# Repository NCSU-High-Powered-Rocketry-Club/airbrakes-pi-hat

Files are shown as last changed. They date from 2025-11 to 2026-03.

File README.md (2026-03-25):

# airbrakes-pi-hat

Custom made Pi hat, named "Airbender", for use in Airbrakes

This repository contains the KiCad project files for a Raspberry Pi hat. This Pi hat is meant to control
airbrakes (see the [airbrakes repository](https://github.com/NCSU-High-Powered-Rocketry-Club/AirbrakesV2) for more details on the airbrakes system).

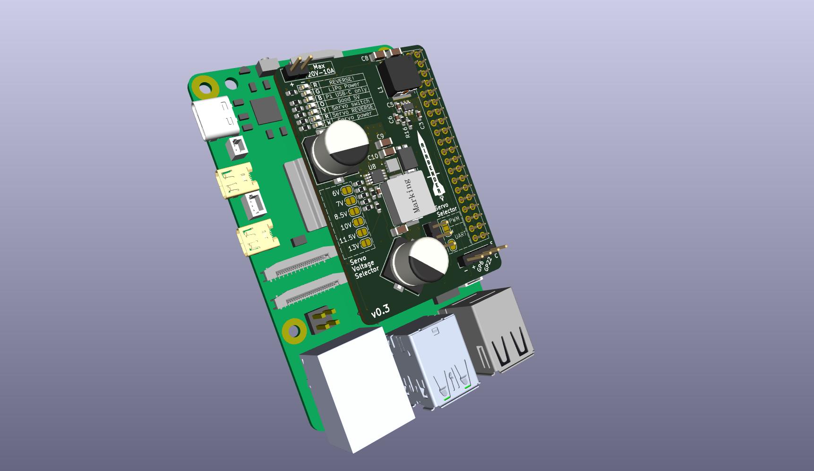
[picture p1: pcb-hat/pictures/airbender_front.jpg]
Airbender Front

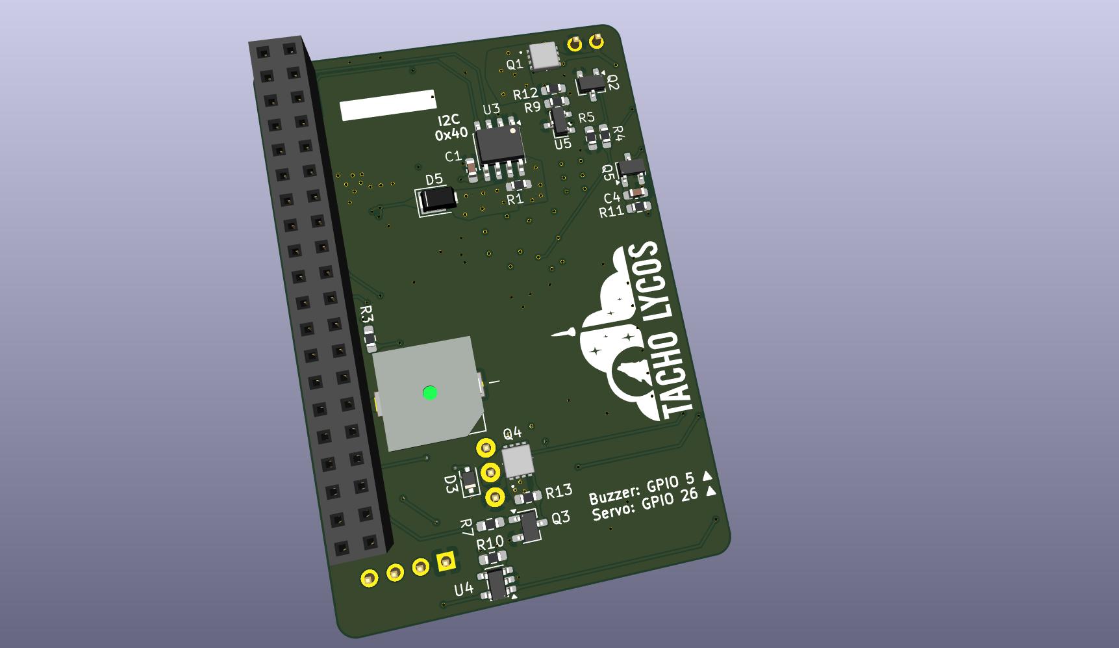
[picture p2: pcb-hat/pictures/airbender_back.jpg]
Airbender Back


## Features

- Supports from 7V to 20V input voltage, with a maximum amperage of 10A.
- Variable output voltage for the servo power rail (6V to 13V), while simultaneously powering the Pi at 5V.
- Current and voltage sensing for the entire board, which allows measurement of servo load transients.
- Reverse polarity detection and protection on the input power rail
- Reverse polarity detection and protection for the servo cable. Plugging in the cable backwards now will not fry the Raspberry Pi.
- 7 LEDs for monitoring and detecting the health of the board and its interface with the Raspberry Pi.
- Solder jumper pad to select using a servo via PWM or communicate with the servo via UART
- P-MOSFET to disable power to the servo rail when not in use
- Software controlled buzzer for audible alerts

The repository includes schematic symbols, PCB footprints, 3D models, and all board files necessary to review, edit and manufacture the module.

---

## Quick Start — open the project

1. Install KiCad (see [Install and Setup](#install-and-setup) below).
2. Clone the repository:
```bash
git clone https://github.com/NCSU-High-Powered-Rocketry-Club/airbrakes-pi-hat.git && cd airbrakes-pi-hat
```

---

## Install and Setup

First, install KiCad from [kicad.org](https://kicad.org/download/). We recommend using the latest stable release of KiCad for new designs.

### After installation
- Open the `pcb-hat.kicad_pro` project. KiCad will use the `sym-lib-table` and `fp-lib-table` files included here if you open the board/schematic from this checkout.
- If KiCad shows missing library warnings, update the Project Library Tables or use the library manager to add the project's `sym-lib-table` and `fp-lib-table`.

---

## Repository structure

Root-level description (key files/folders):

- `milled_ab_pi_hat/` — folder containing CNC milling files for in-house fabrication at the ECE Makerspace
- `pcb-hat/` — folder which contains the project files for the SMD version of the Pi hat (This is what we order from JLCPCB!)
- `pcb-hat.kicad_sch` — schematic
- `pcb-hat.kicad_pcb` — PCB layout
- `pcb-hat.kicad_pro` — KiCad project file that links schematics, board and library tables
- `sym-lib-table` — project symbol library table that makes project-local symbols available to Eeschema
- `fp-lib-table` — project footprint library table that makes project-local footprints available
- `3dmodels/` — 3D STEP/WRL models used with footprints
- `symbols/` — human-editable symbol libraries (e.g., `connectors.kicad_sym`, `sensors.kicad_sym`)
- `footprints/` — footprint libraries as `.pretty` directories

---

## Library handling

We keep the project-specific libraries inside the repository so that board designs are reproducible and self-contained.

### Symbols
- New symbols are added to the project's `symbols` directory and are registered in the project's `sym-lib-table`.

### Footprints
- Footprints live inside `.pretty` folders in `footprints/`. Add footprints via the footprint editor and store them in an appropriate `footprints/<libname>.pretty` folder.

### 3D models
- 3D models are stored in `3dmodels/` and referenced by footprint model paths. Keep STEP files with good orientation and scale (KiCad's default is mm). We typically download the .step file from the manufacturer's website.
- If you add a footprint that references a 3D model, commit both the footprint in `footprints/` and the 3D model to `3dmodels/`.

---

## Good Practices & Design Rules

- Keep schematic symbols generic and footprints specific: do not hardcode assembly-side changes into symbols.
- Look at the existing schematic to see how we do things and try to be consistent.
- Save new libraries to the project-local tables (not global) to keep designs reproducible.
- Keep PCB footprints accurate — use accurate courtyard, 3D models, and update packaging information.
- Validate with DRC (PCB Editor > Inspect > Design Rules Checker) and ERC (Eeschema > Tools > ERC) before committing changes.
- When collaborating, include notes about part sources (Mouser/Digikey vendor links), footprints used, and any custom pad or thickness changes.

---

## Release & Manufacturing Checklist

Before requesting fab or assembling a board, run this checklist:
1. Run ERC (Eeschema > Tools > ERC) and fix all warnings.
2. Run DRC in PCB Editor and resolve all errors.
3. Create a BOM and confirm manufacturer part numbers and footprints match.
4. Get the [Fabrication Toolkit](https://github.com/bennymeg/Fabrication-Toolkit) plugin from the KiCad plugin repo
5. Click the generate gerber files button in the PCB editor (via the plugin). Keep all default options. Then export it. 
6. Check 3D model alignment in PCB Editor (View > 3D Viewer) to ensure components fit.
7. Tag or branch the repo in Git to preserve the release snapshot.

---

## License

See `LICENSE` at the repo root for licensing details.

---

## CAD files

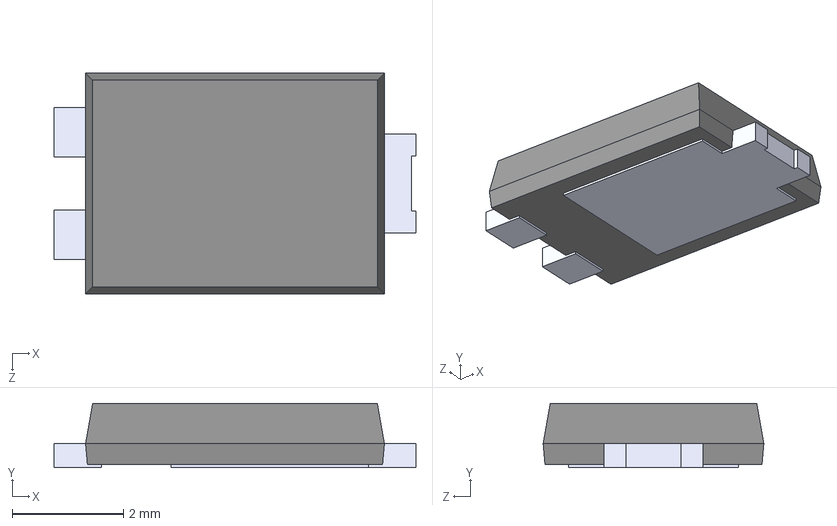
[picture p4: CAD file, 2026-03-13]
pcb-hat/3dmodels/SBR10E45P5-13D.STEP
6.50 x 1.15 x 3.97 mm

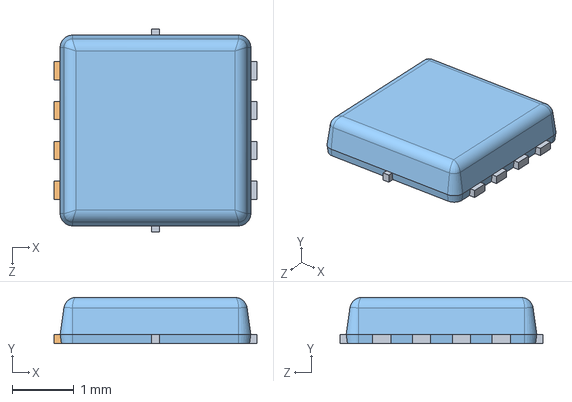
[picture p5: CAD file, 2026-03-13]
pcb-hat/3dmodels/PJQ4437EP-AU.stp
3.30 x 0.75 x 3.30 mm
LeadFrame
EMC

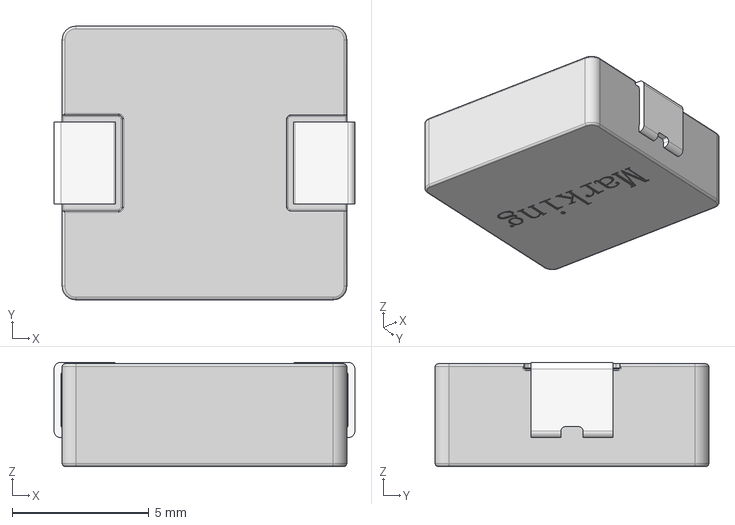
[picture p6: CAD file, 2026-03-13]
pcb-hat/3dmodels/3D_SRP1038CC SERIES(leadframe type).stp
11.0 x 10.0 x 3.81 mm

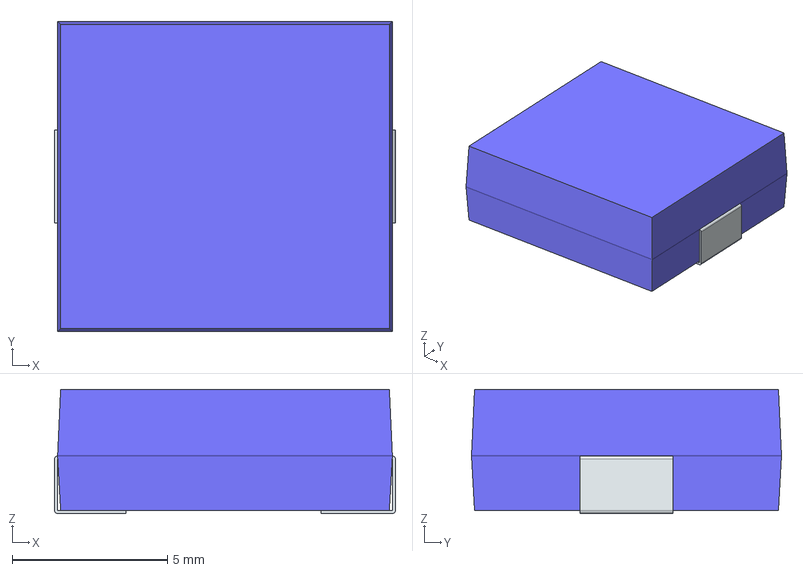
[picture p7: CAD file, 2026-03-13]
pcb-hat/3dmodels/SRP1038CC-4R7M.stp
11.0 x 10.0 x 4.00 mm
FilletPin1
FilletPin2

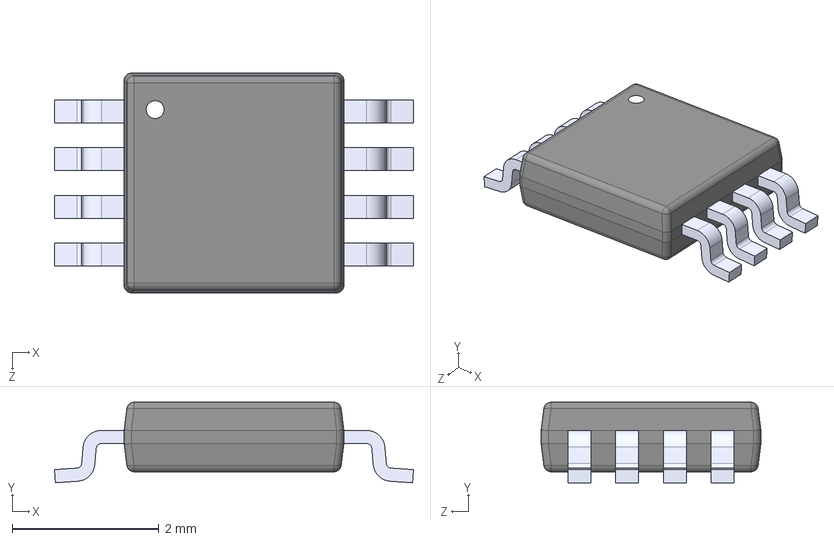
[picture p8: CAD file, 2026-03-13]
pcb-hat/3dmodels/LM3489MMX_NOPB.step
4.90 x 1.10 x 3.00 mm

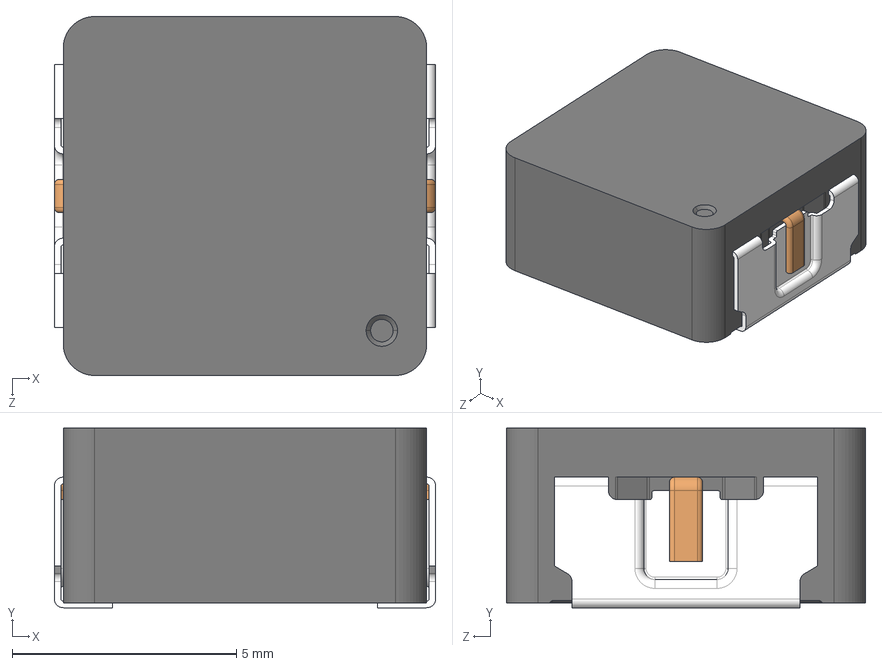
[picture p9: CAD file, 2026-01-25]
pcb-hat/3dmodels/ETQP4M6R8KVK.step
8.50 x 4.00 x 8.00 mm

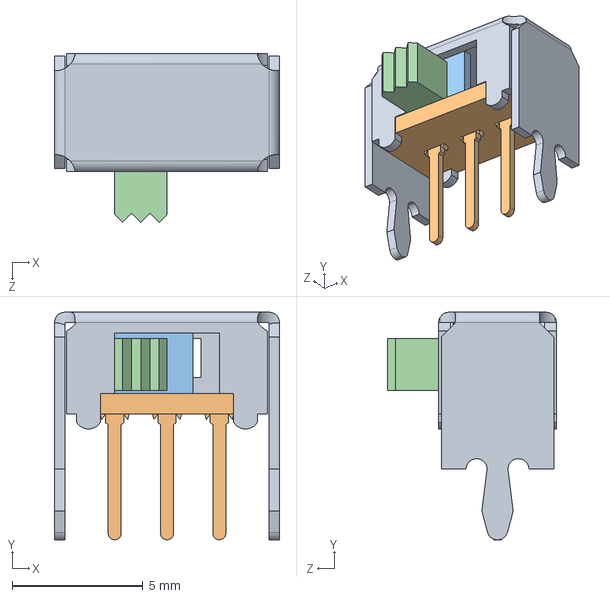
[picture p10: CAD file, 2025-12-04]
pcb-hat/3dmodels/SLW-864587-2A-RA-N-D.step
8.60 x 8.70 x 6.45 mm

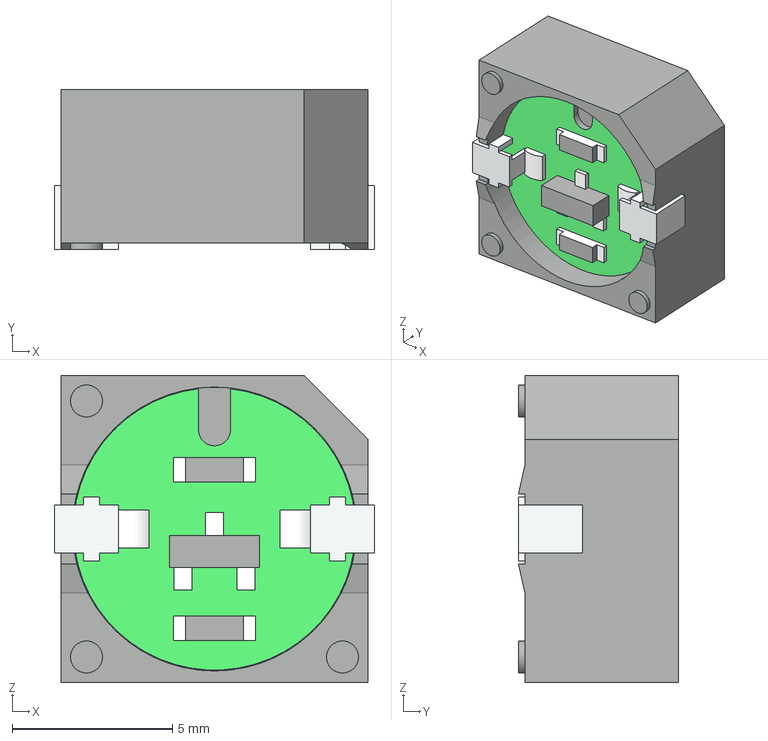
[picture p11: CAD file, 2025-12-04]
pcb-hat/3dmodels/SMI-1027-T-5V-R.step
10.0 x 5.00 x 9.60 mm

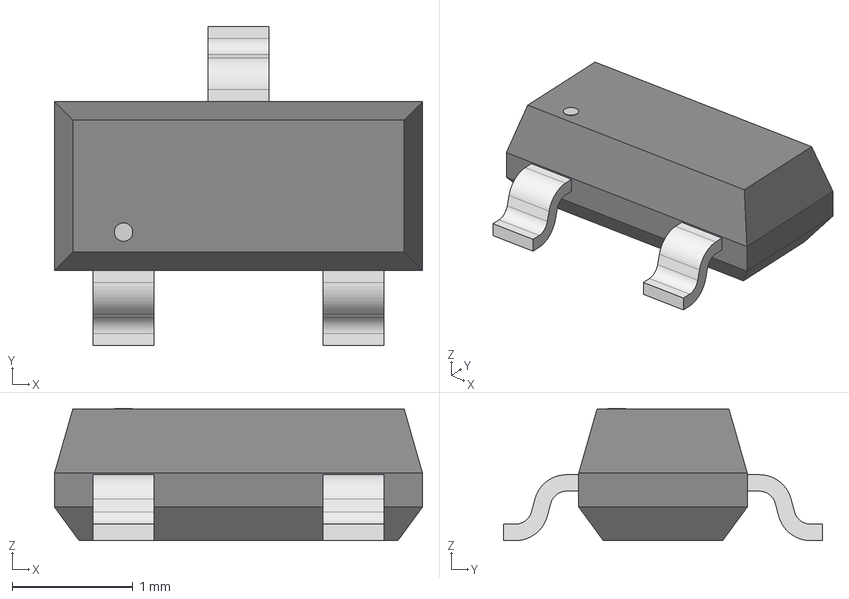
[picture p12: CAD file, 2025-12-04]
pcb-hat/3dmodels/MTR_MMBT2222A-TP_MCE.step
3.05 x 2.64 x 1.09 mm

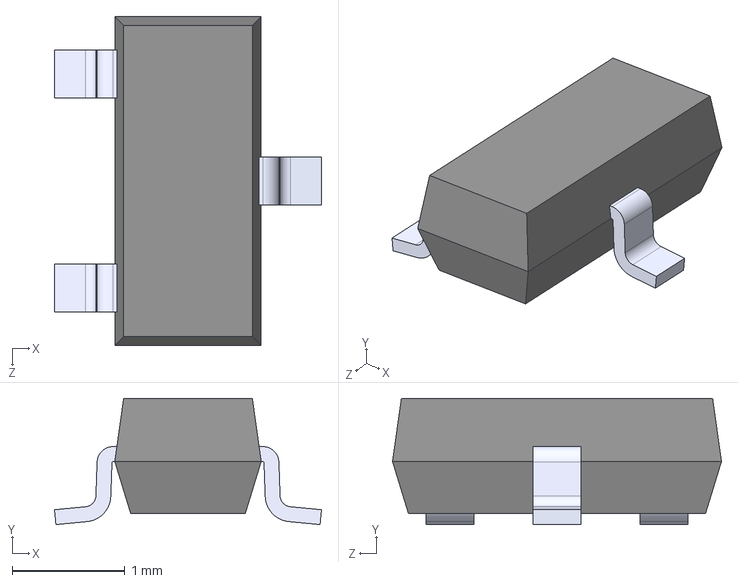
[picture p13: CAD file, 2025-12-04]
pcb-hat/3dmodels/SI2347DS-T1-GE3.STEP
2.37 x 1.12 x 2.92 mm

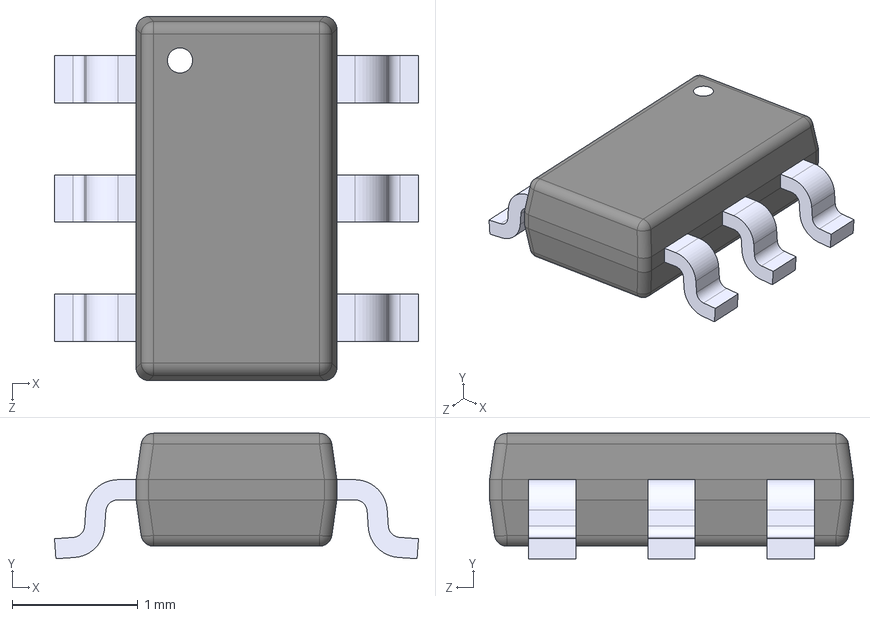
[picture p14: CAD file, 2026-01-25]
pcb-hat/3dmodels/AP63300WU-7.step
2.90 x 1.00 x 2.90 mm

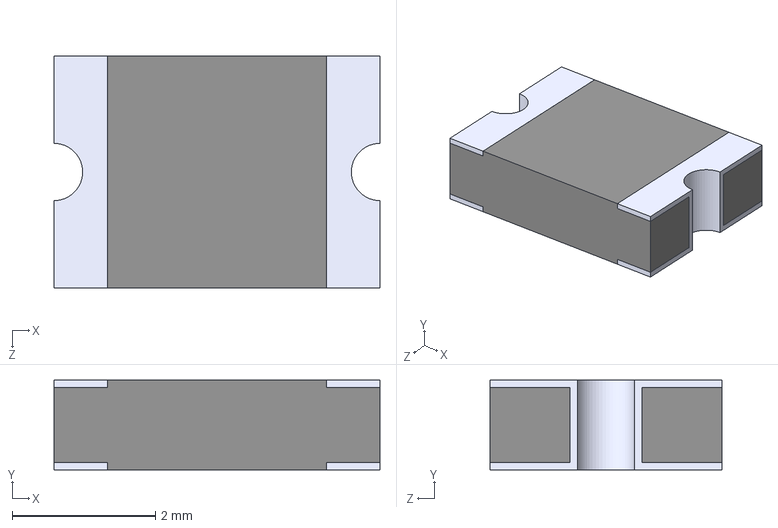
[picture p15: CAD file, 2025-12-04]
pcb-hat/3dmodels/1812L110_24DR.step
4.55 x 1.25 x 3.24 mm

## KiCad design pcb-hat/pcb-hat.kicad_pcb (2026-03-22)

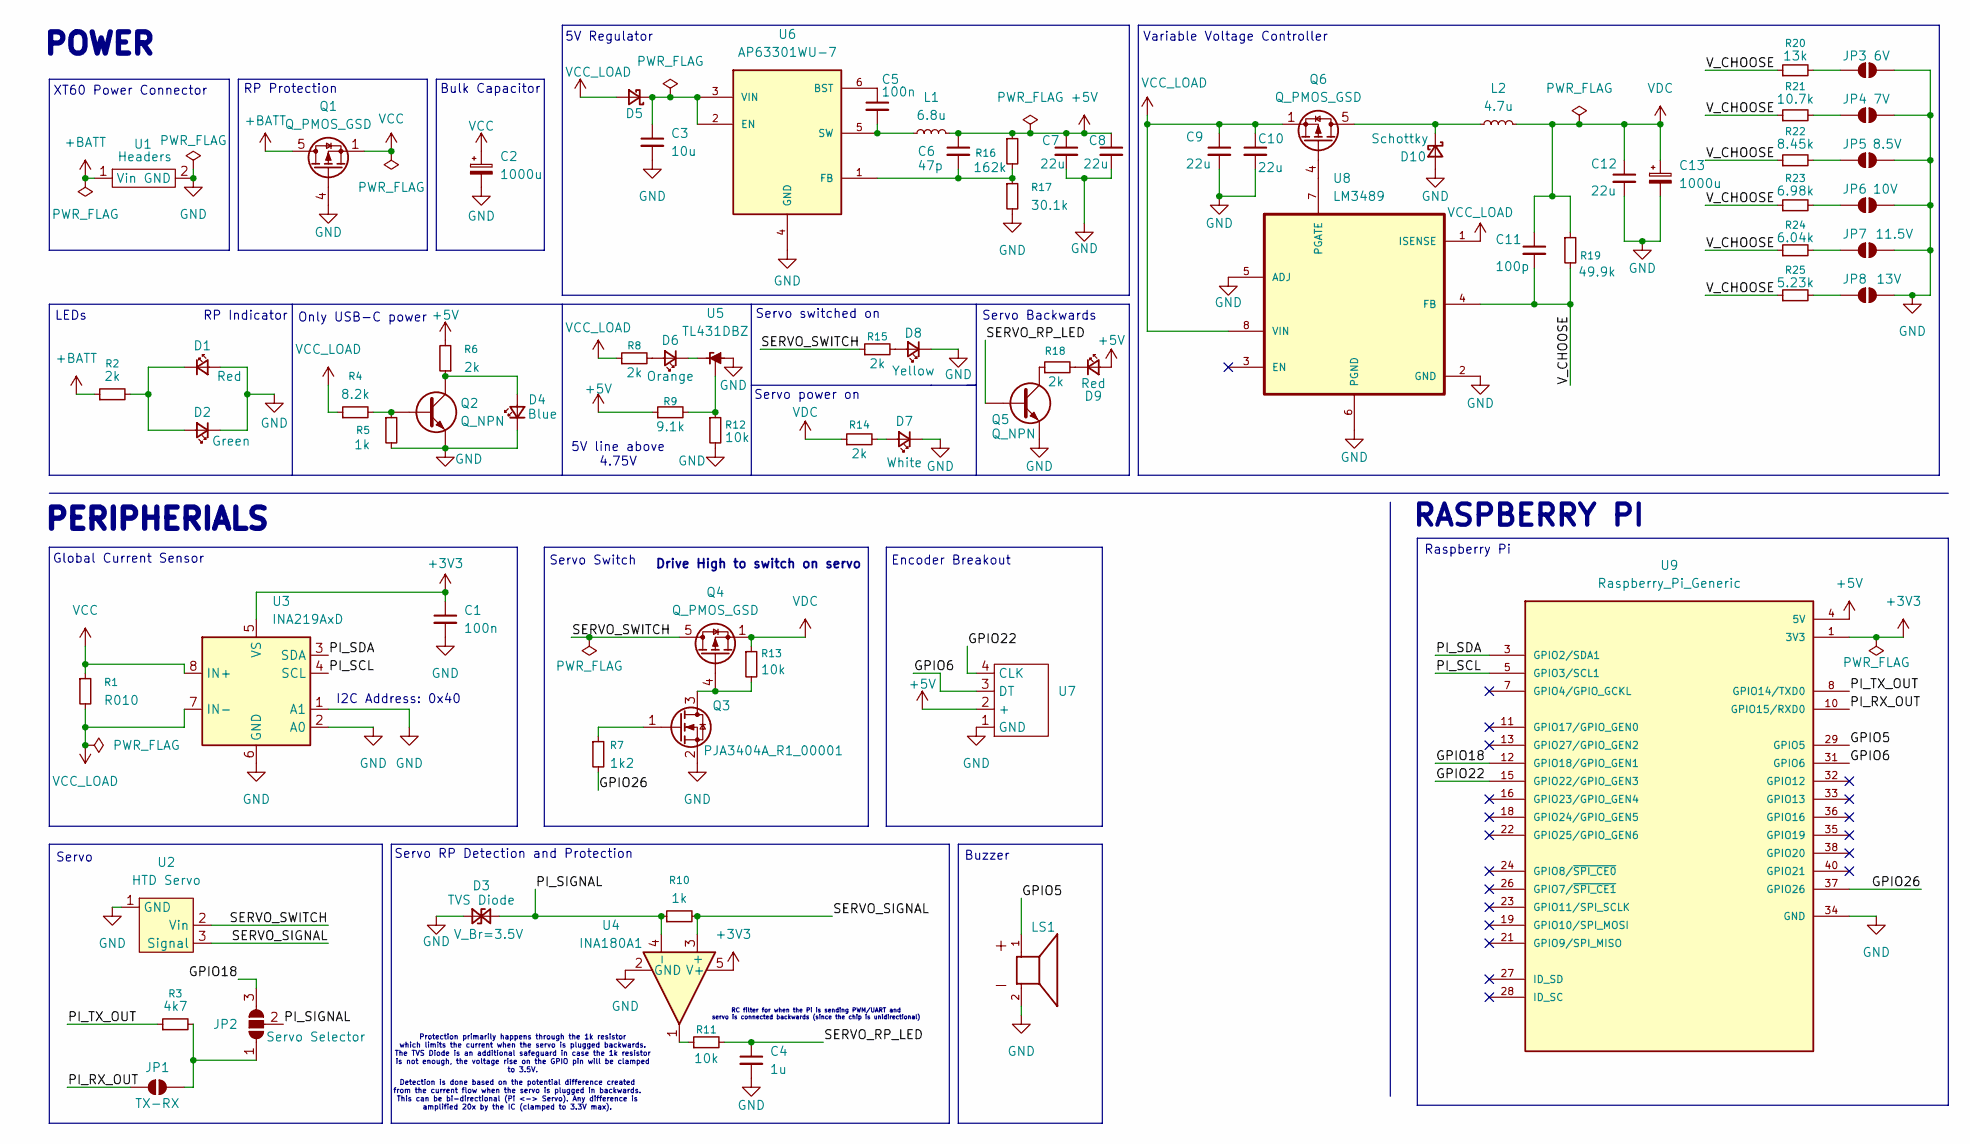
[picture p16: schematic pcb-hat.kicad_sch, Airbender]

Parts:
C1, C5: 100n; C_0603_1608Metric_Pad1.08x0.95mm_HandSolder; Digikey PN C0603C104K3RACTU
C2, C13: 1000u; CP_Elec_10x10.5; Digikey PN 399-A783MW108M1ELAS011CT-ND
C3: 10u; C_0603_1608Metric_Pad1.08x0.95mm_HandSolder; Digikey PN 1276-1869-1-ND
C4: 1u; C_0603_1608Metric_Pad1.08x0.95mm_HandSolder; Digikey PN 587-3247-1-ND
C6: 47p; C_0603_1608Metric_Pad1.08x0.95mm_HandSolder; Digikey PN 720-VJ0603A470JXXPW1BCCT-ND
C7, C8, C9, C10, C12: 22u; C_1206_3216Metric; Digikey PN 587-3246-1-ND
C11: 100p; C_0603_1608Metric_Pad1.08x0.95mm_HandSolder; Digikey PN 399-C0603C101J5GACTUCT-ND
D1, D9: LED_Small; LED_0603_1608Metric_Pad1.05x0.95mm_HandSolder; Digikey PN 475-LSQ976.01-N1Q2-1-20-R18CT-ND
D2: LED_Small; LED_0603_1608Metric_Pad1.05x0.95mm_HandSolder; Digikey PN 160-LTST-C190GKTCT-ND
D3: TVS Diode; D_SOD-323F; Digikey PN F6271CT-ND
D4: LED_Small; LED_0603_1608Metric_Pad1.05x0.95mm_HandSolder; Digikey PN 160-1837-1-ND
D5: SS3P4-M3/84A; D_SMP_DO-220AA; Digikey PN SS3P4-M3/84AGICT-ND
D6: LED_Small; LED_0603_1608Metric_Pad1.05x0.95mm_HandSolder; Digikey PN 475-LOQ976.01-P2R2-25-1-20-R18CT-ND
D7: LED_Small; LED_0603_1608Metric_Pad1.05x0.95mm_HandSolder; Digikey PN 350-5992000147FCT-ND
D8: LED_Small; LED_0603_1608Metric_Pad1.05x0.95mm_HandSolder; Digikey PN 160-1437-1-ND
D10: Schottky; D_PowerDI-5; Digikey PN SBR10E45P5-7DICT-ND
JP1: TX to RX?; SolderJumper-2_P1.3mm_Open_RoundedPad1.0x1.5mm
JP2: Servo Selector; SolderJumper-3_P1.3mm_Open_RoundedPad1.0x1.5mm
JP3, JP4, JP5, JP6, JP7, JP8: SolderJumper_2_Open; SolderJumper-2_P1.3mm_Open_RoundedPad1.0x1.5mm
L1: 6.8u; IND_ETQP4M6R8KVK; Digikey PN P19775CT-ND
L2: 4.7u; L_Bourns_SRP1038C_10.0x10.0mm; Digikey PN SRP1038CC-4R7M
LS1: XDCR_SMI-1027-T-5V-R; PARTREV 03/26/2020; Digikey PN smi-1027-t-5v-r
Q1, Q4, Q6: Q_PMOS_GSD; PJQ4465APAU_R2_000A1; Digikey PN 3757-PJQ4437EP-AU_R2_002A1CT-ND
Q2, Q5: Q_NPN; TSOT-23; Digikey PN MMBT2222A-TP
Q3: PJA3404A_R1_00001; TSOT-23; Digikey PN 3757-PJA3404A_R1_00001CT-ND
R1: R010; R_0603_1608Metric_Pad0.98x0.95mm_HandSolder; Digikey PN PE0603FRE570R01Z
R2, R6, R8, R14, R15: 2k; R_0603_1608Metric_Pad0.98x0.95mm_HandSolder; Digikey PN ERJ-PA3J202V
R3: 4k7; R_0603_1608Metric_Pad0.98x0.95mm_HandSolder; Digikey PN RC0603FR-074K7L
R4: 8.2k; R_0603_1608Metric_Pad0.98x0.95mm_HandSolder; Digikey PN 311-8.2KGRCT-ND
R5, R10: 1k; R_0603_1608Metric_Pad0.98x0.95mm_HandSolder; Digikey PN RMCF0603FT1K00CT-ND
R7: 1k2; R_0603_1608Metric_Pad0.98x0.95mm_HandSolder; Digikey PN ERA-3AEB122V
R9: 9.1k; R_0603_1608Metric_Pad0.98x0.95mm_HandSolder; Digikey PN RMCF0603FT9K10CT-ND
R11, R12, R13: 10k; R_0603_1608Metric_Pad0.98x0.95mm_HandSolder; Digikey PN 311-10.0KHRCT-ND
R16: 162k; R_0603_1608Metric_Pad0.98x0.95mm_HandSolder; Digikey PN 541-162KHCT-ND
R17: 30.1k; R_0603_1608Metric_Pad0.98x0.95mm_HandSolder; Digikey PN RMCF0603FT30K1CT-ND
R18: 2k; R_0603_1608Metric_Pad0.98x0.95mm_HandSolder; Digikey PN RMCF0603FT1K00CT-ND
R19: 49.9k; R_0603_1608Metric_Pad0.98x0.95mm_HandSolder; Digikey PN P49.9KDBCT-ND
R20: 13k; R_0603_1608Metric_Pad0.98x0.95mm_HandSolder; Digikey PN 2019-RK73H1JTTD1302FCT-ND
R21: 10.7k; R_0603_1608Metric_Pad0.98x0.95mm_HandSolder; Digikey PN 311-10.7KHRCT-ND
R22: 8.45k; R_0603_1608Metric_Pad0.98x0.95mm_HandSolder; Digikey PN 311-8.45KHRCT-ND
R23: 6.98k; R_0603_1608Metric_Pad0.98x0.95mm_HandSolder; Digikey PN 10-ERA-3AEB6981VCT-ND
R24: 6.04k; R_0603_1608Metric_Pad0.98x0.95mm_HandSolder; Digikey PN 311-6.04KHRCT-ND
R25: 5.23k; R_0603_1608Metric_Pad0.98x0.95mm_HandSolder; Digikey PN 311-5.23KHRCT-ND
U1: Headers; XT60
U2: HTD Servo; Servo
U3: INA219AxD; SOIC-8_3.9x4.9mm_P1.27mm; Digikey PN INA219AIDR
U4: INA180A1; SOT-23-5; Digikey PN 296-47652-1-ND
U5: TL431DBZ; SOT-23; Digikey PN 5399-TL431CT-ND
U6: AP63301WU-7; SOT95P280X100-6N; Digikey PN 31-AP63301WU-7CT-ND
U7: PinHeader_1x04_P2.54mm_Vertical
U8: LM3489; SOP65P490X110-8N; Digikey PN 296-35277-1-ND
U9: Raspberry_Pi_Generic; Pi5Hat

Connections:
+3V3: C1.1, U3.5 (VS), U4.5 (V+), U9.1 (3V3), U9.17 (3V3)
+5V: C6.1, C7.1, C8.1, D9.2 (A), L1.2, R6.2, R9.1, R16.1, U7.2 (+), U9.2 (5V), U9.4 (5V)
+BATT: Q1.5 (D), Q1.6 (D), Q1.7 (D), Q1.8 (D), Q1.9 (D), R2.1, U1.1 (Vin)
/GPIO5: LS1.1, U9.29 (GPIO5)
/GPIO6: U7.3 (DT), U9.31 (GPIO6)
/GPIO18: JP2.3 (B), U9.12 (GPIO18/GPIO_GEN1)
/GPIO22: U7.4 (CLK), U9.15 (GPIO22/GPIO_GEN3)
/GPIO26: R7.2, U9.37 (GPIO26)
/PI_RX_OUT: JP1.1 (A), U9.10 (GPIO15/RXD0)
/PI_SCL: U3.4 (SCL), U9.5 (GPIO3/SCL1)
/PI_SDA: U3.3 (SDA), U9.3 (GPIO2/SDA1)
/PI_SIGNAL: D3.2 (A2), JP2.2 (C), R10.1, U4.4 (-)
/PI_TX_OUT: R3.1, U9.8 (GPIO14/TXD0)
/SERVO_RP_LED: C4.1, Q5.1 (B), R11.2
/SERVO_SIGNAL: R10.2, U2.3 (Signal), U4.3 (+)
/SERVO_SWITCH: Q4.5 (D), Q4.6 (D), Q4.7 (D), Q4.8 (D), Q4.9 (D), R15.1, U2.2 (Vin)
/V_CHOOSE: C11.2, R19.2, R20.1, R21.1, R22.1, R23.1, R24.1, R25.1, U8.4 (FB)
GND: C1.2, C2.2, C3.2, C4.2, C7.2, C8.2, C9.2, C10.2, C12.2, C13.2, D1.2 (A), D2.1 (K), D3.1 (A1), D4.1 (K), D7.1 (K), D8.1 (K), D10.2 (A), JP3.2 (B), JP4.2 (B), JP5.2 (B), JP6.2 (B), JP7.2 (B), JP8.2 (B), LS1.2, Q1.4 (G), Q2.2 (E), Q3.2 (S), Q5.2 (E), R5.2, R12.2, R17.2, U1.2 (GND), U2.1 (GND), U3.1 (A1), U3.2 (A0), U3.6 (GND), U4.2 (GND), U5.3 (A), U6.4 (GND), U7.1 (GND), U8.2 (GND), U8.5 (ADJ), U8.6 (PGND), U9.6 (GND), U9.9 (GND), U9.14 (GND), U9.20 (GND), U9.25 (GND), U9.30 (GND), U9.34 (GND), U9.39 (GND)
unnamed: D1.1 (K), D2.2 (A), R2.2
unnamed: D4.2 (A), Q2.3 (C), R6.1
unnamed: C3.1, D5.1 (K), U6.2 (EN), U6.3 (VIN)
unnamed: D6.2 (A), R8.2
unnamed: D6.1 (K), U5.1 (K)
unnamed: D7.2 (A), R14.2
unnamed: D8.2 (A), R15.2
unnamed: D9.1 (K), R18.2
unnamed: D10.1 (K), L2.1, Q6.5 (D), Q6.6 (D), Q6.7 (D), Q6.8 (D), Q6.9 (D)
unnamed: JP1.2 (B), JP2.1 (A), R3.2
unnamed: JP3.1 (A), R20.2
unnamed: JP4.1 (A), R21.2
unnamed: JP5.1 (A), R22.2
unnamed: JP6.1 (A), R23.2
unnamed: JP7.1 (A), R24.2
unnamed: JP8.1 (A), R25.2
unnamed: Q2.1 (B), R4.2, R5.1
unnamed: Q3.3 (D), Q4.4 (G), R13.2
unnamed: Q3.1 (G), R7.1
unnamed: Q5.3 (C), R18.1
unnamed: Q6.4 (G), U8.7 (PGATE)
unnamed: R11.1, U4.1
unnamed: R9.2, R12.1, U5.2 (REF)
unnamed: C5.1, U6.6 (BST)
unnamed: C6.2, R16.2, R17.1, U6.1 (FB)
unnamed: C5.2, L1.1, U6.5 (SW)
VCC: C2.1, Q1.1 (S), Q1.2 (S), Q1.3 (S), R1.1, U3.8 (IN+)
VCC_LOAD: C9.1, C10.1, D5.2 (A), Q6.1 (S), Q6.2 (S), Q6.3 (S), R1.2, R4.1, R8.1, U3.7 (IN-), U8.1 (ISENSE), U8.8 (VIN)
VDC: C11.1, C12.1, C13.1, L2.2, Q4.1 (S), Q4.2 (S), Q4.3 (S), R13.1, R14.1, R19.1

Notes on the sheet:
Global Current Sensor
Buzzer
PERIPHERIALS
Servo RP Detection and Protection
Servo
Encoder Breakout
LEDs
XT60 Power Connector
POWER
I2C Address: 0x40
Drive High to switch on servo
Servo Switch
Protection primarily happens through the 1k resistor which limits the current when the servo is plugged backwards. The TVS Diode is an additional safeguard in case the 1k resistor is not enough, the voltage rise on the GPIO pin will be clamped to 3.5V.
Servo power on
Servo switched on
Detection is done based on the potential difference created from the current flow when the servo is plugged in backwards. This can be bi-directional (Pi <-> Servo). Any difference is amplified 20x by the IC (clamped to 3.3V max).
Only USB-C power
RC filter for when the Pi is sending PWM/UART and servo is connected backwards (since the chip is unidirectional)
Bulk Capacitor
Variable Voltage Controller
RASPBERRY PI
5V line above 4.75V
RP Protection
5V Regulator
Raspberry Pi
Servo Backwards
RP Indicator

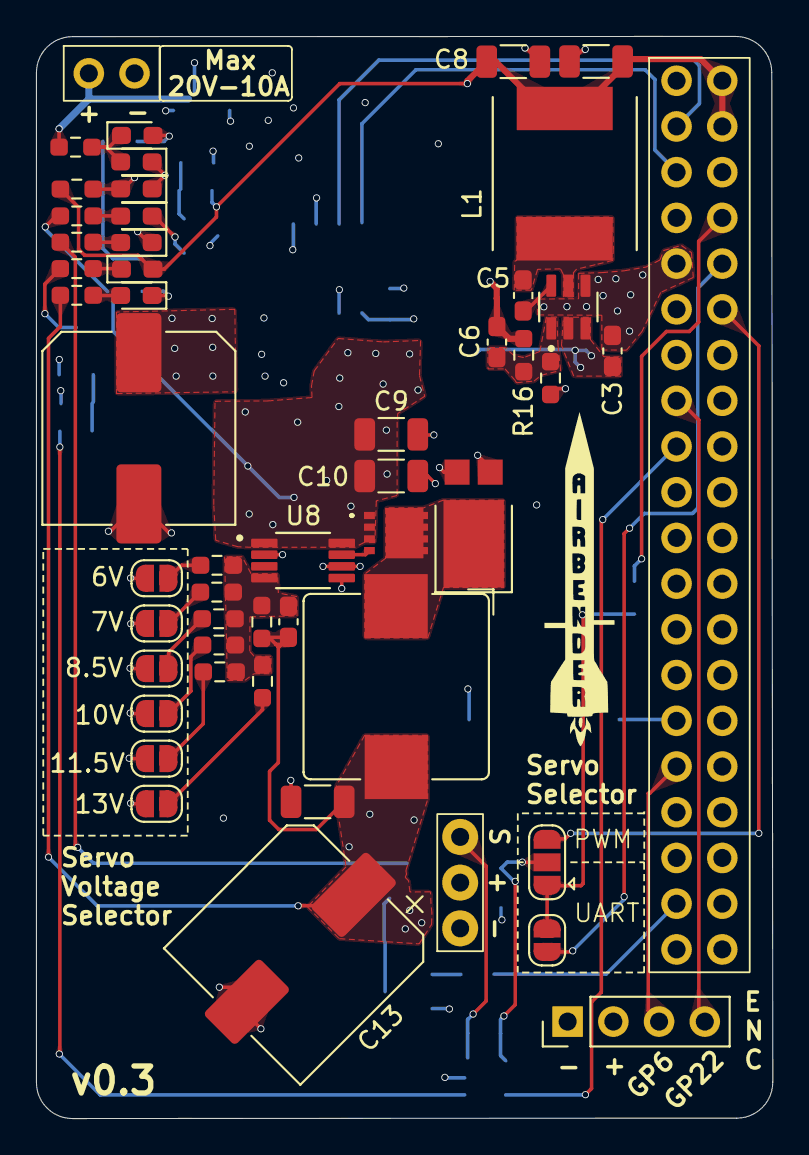
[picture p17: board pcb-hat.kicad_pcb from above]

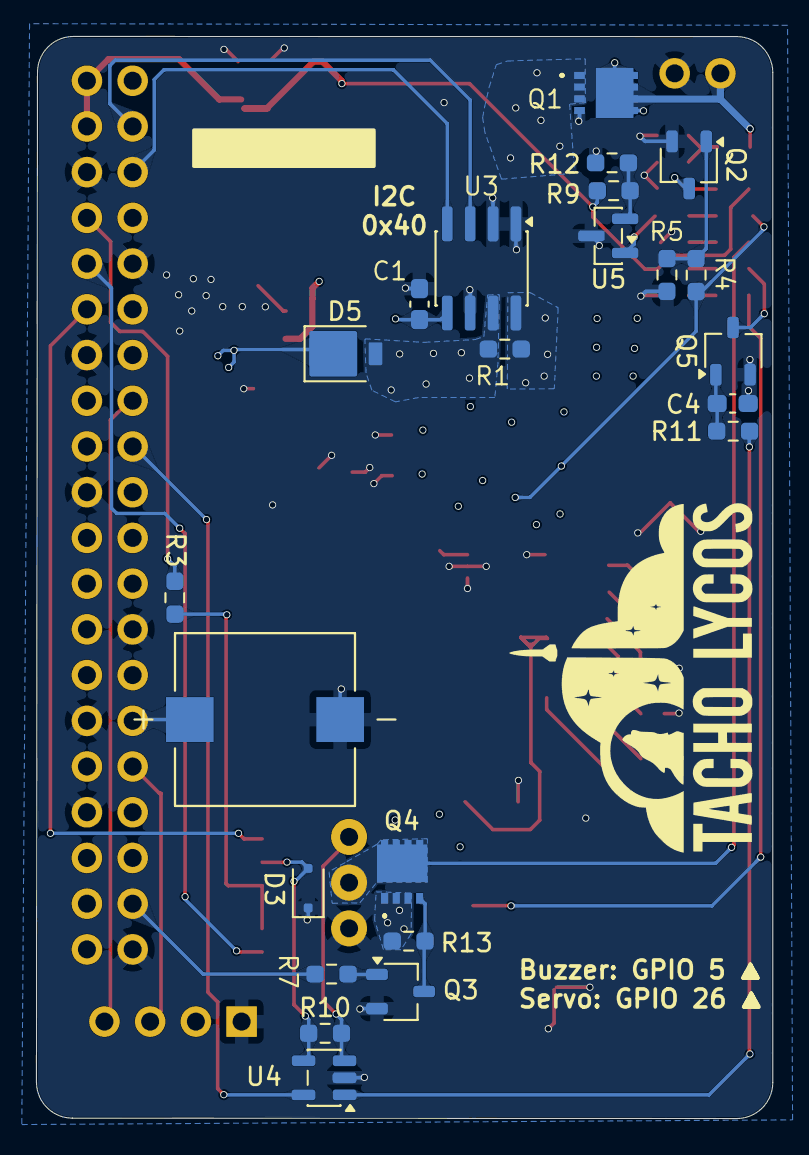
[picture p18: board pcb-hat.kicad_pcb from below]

Board: 4 copper layers, 40.9 x 60.1 mm, 75 parts (23 on the bottom side), 47 nets.

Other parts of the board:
RPi5: RPi5; Raspberry Pi 5

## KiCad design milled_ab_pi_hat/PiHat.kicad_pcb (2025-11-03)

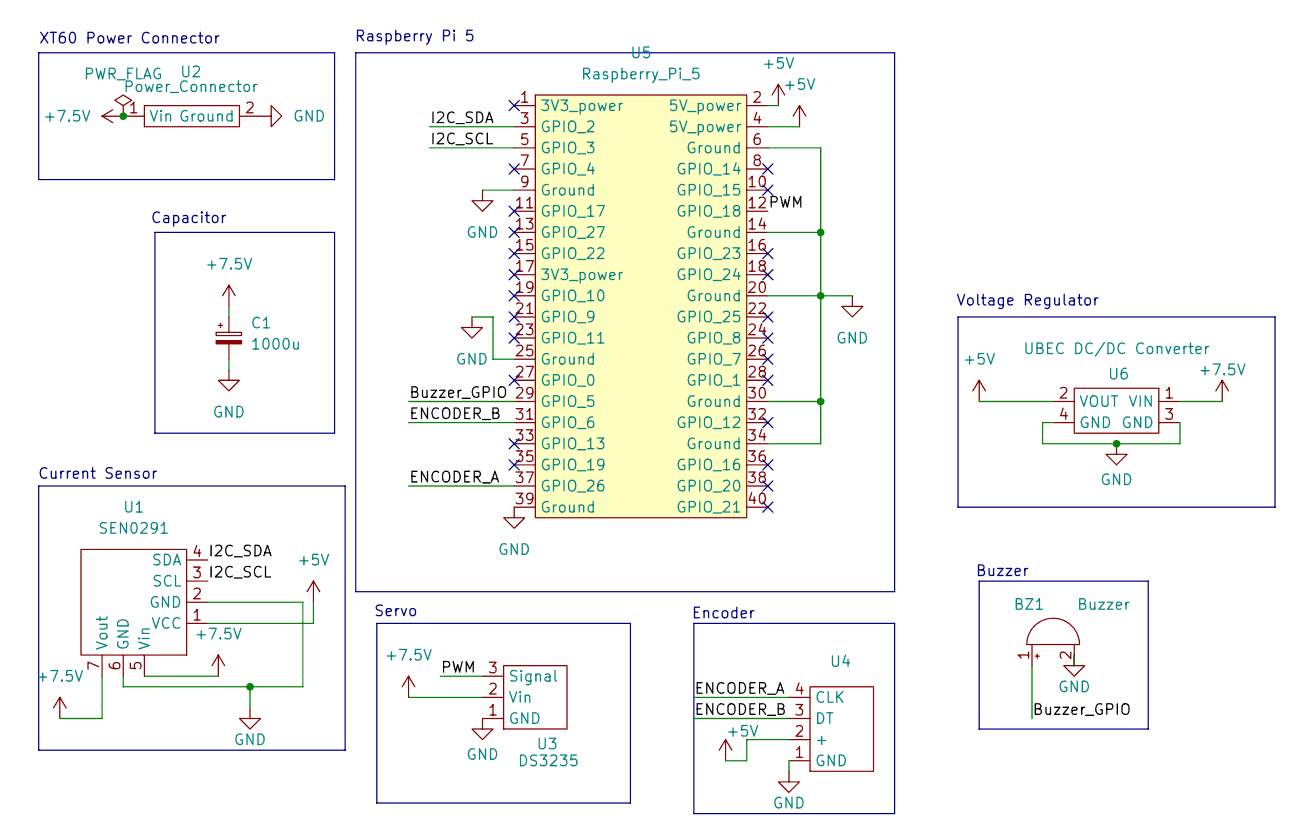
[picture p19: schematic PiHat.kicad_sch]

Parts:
BZ1: Buzzer; Buzzer_12x9.5RM7.6
C1: 1000u; BigCapacitor
U1: SEN0291; CurrentSensor
U2: Power_Connector; XT60
U3: DS3235; Servo
U4: Encoder
U5: Raspberry_Pi_5; Pi5Hat
U6: UBEC DC/DC Converter; UBEC 5V Step Down

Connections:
+5V: U1.1 (VCC), U4.2 (+), U5.2 (5V_power), U5.4 (5V_power), U6.2 (VOUT)
+7.5V: C1.1, U1.5 (Vin), U1.7 (Vout), U2.1 (Vin), U3.2 (Vin), U6.1 (VIN)
/Buzzer_GPIO: BZ1.1 (+), U5.29 (GPIO_5)
/ENCODER_A: U4.4 (CLK), U5.37 (GPIO_26)
/ENCODER_B: U4.3 (DT), U5.31 (GPIO_6)
/I2C_SCL: U1.3 (SCL), U5.5 (GPIO_3)
/I2C_SDA: U1.4 (SDA), U5.3 (GPIO_2)
/PWM: U3.3 (Signal), U5.12 (GPIO_18)
GND: BZ1.2 (-), C1.2, U1.2 (GND), U1.6 (GND), U2.2 (Ground), U3.1 (GND), U4.1 (GND), U5.6 (Ground), U5.9 (Ground), U5.14 (Ground), U5.20 (Ground), U5.25 (Ground), U5.30 (Ground), U5.34 (Ground), U5.39 (Ground), U6.3 (GND), U6.4 (GND)

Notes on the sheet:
Capacitor
Current Sensor
Encoder
XT60 Power Connector
Buzzer
Raspberry Pi 5
Servo
Voltage Regulator

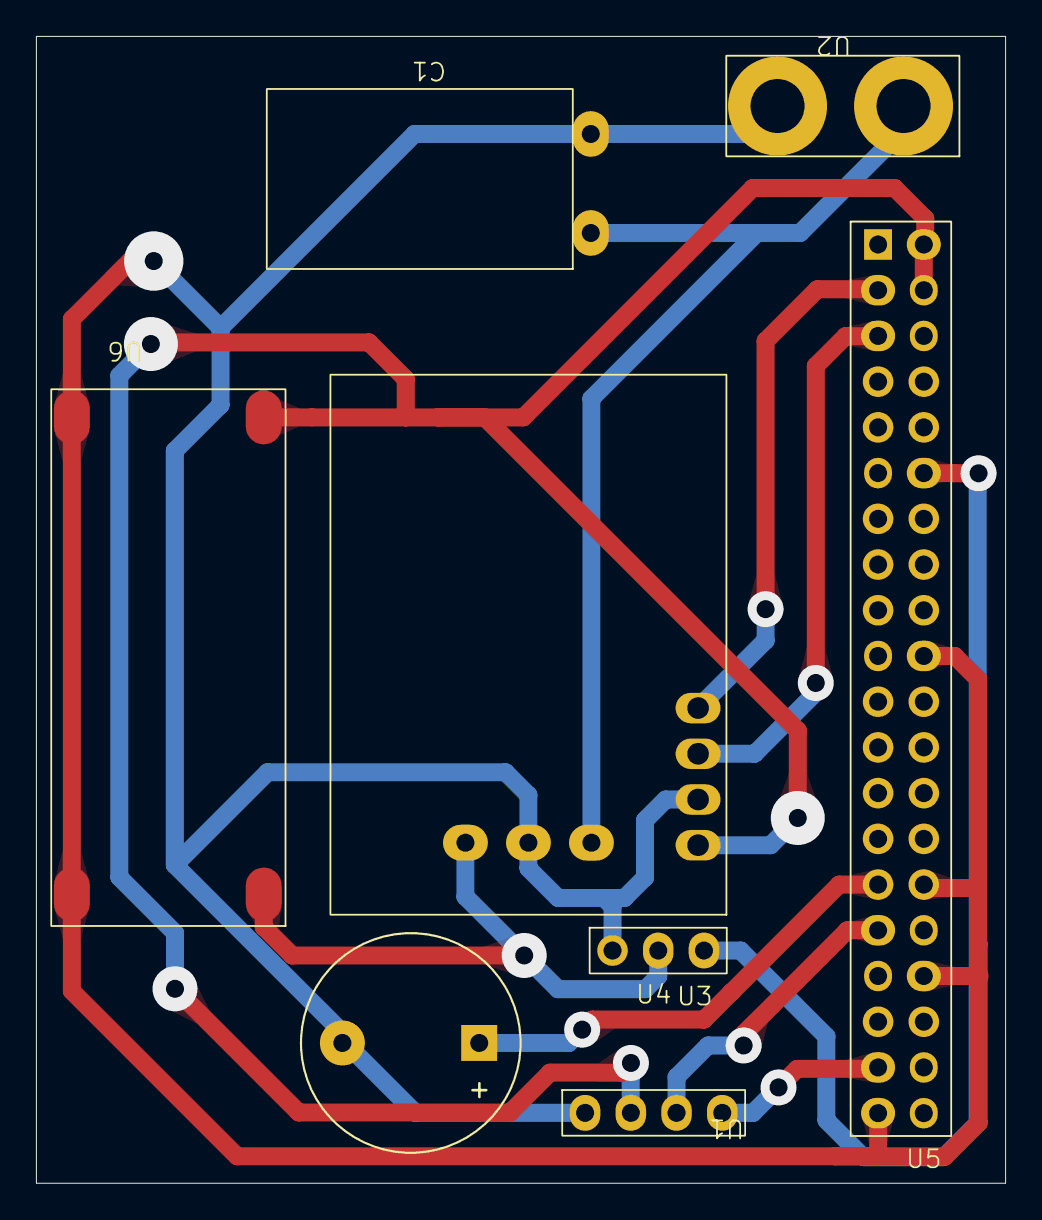
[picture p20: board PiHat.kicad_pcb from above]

Board: 2 copper layers, 53.8 x 63.7 mm, 8 parts (0 on the bottom side), 9 nets.

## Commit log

2025-11-03 Add old AB pi hat
    [PiHat-B_Cu.gbr, PiHat-B_Mask.gbr, PiHat-B_Paste.gbr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]
2025-11-05 Add pcb hat directory
    [pcb-hat.kicad_pcb, pcb-hat.kicad_sch]
2025-11-05 added SMD buzzer and current sensor
    [pcb-hat.kicad_sch]
2025-11-06 Finish current sensor & buzzer wiring
    [SMI-1027-T-5V-R.step, pcb-hat.kicad_sch]
2025-11-08 5V Converter sym/footprint and variable regulator sym/footprint/3dmodule added to files
    [AOZ6605PI-1.step, pcb-hat.kicad_sch]
2025-11-09 Almost finish main voltage regulator
    only pot is left
    [SRN8040TA-4R7M.step, pcb-hat.kicad_sch]
2025-11-10 Rearrange stuff
    [pcb-hat.kicad_sch]
2025-11-10 Added solder jumps and resistors
    [pcb-hat.kicad_sch]
2025-11-11 Resistance values and Decoupling capacitor added
    [pcb-hat.kicad_sch]
2025-11-11 LED added
    [pcb-hat.kicad_sch]
2025-11-12 Add Pi, LED, Servo to the schematic
    [pcb-hat.kicad_sch]
2025-11-12 Add new 5V regulator part, finish Servo connection
    Also fix footprint of 7, 8, and 9V resistors to 0603 hand soldered
    [pcb-hat.kicad_sch]
2025-11-12 oop forgot to add the new step and footprint files
    [LM1084ISX-5.0_NOPB.step]
2025-11-12 Update pcb-hat.kicad_sch
    replaced 5v regulator
    [pcb-hat.kicad_sch]
2025-11-12 Update PiHatComponents.kicad_sym
    horizontal breakouts
2025-11-12 Update PiHatComponents.kicad_sym
    vertical breakouts
2025-11-14 WIP: Add breakouts to schematic
    [pcb-hat.kicad_sch]
2025-11-14 symbol/footprint/connections for PiHeaders/pinouts
    [pcb-hat.kicad_sch]
2025-11-15 pi breakout symbol changes
    [pcb-hat.kicad_sch]
2025-11-17 Don't short pwr to gnd for current sensor
    Also use higher power rating for shunt
    [pcb-hat.kicad_sch]
2025-11-18 Add mosfets, new led, and cleanup schematic some more
    [NTMFS5C468NLT1G.stp, pcb-hat.kicad_sch]
2025-11-18 TODO: Add gate resistors on mosfets
    [pcb-hat.kicad_sch]
2025-11-19 Create horizontal_breakout_footprint.kicad_mod
    horizontal breakout footprint
2025-11-19 Switch out the 5V regulator
    [pcb-hat.kicad_sch]
2025-11-20 Cleanup: Add pwr_flags, reference designators, delete old 5v regulator from symbol library
    [pcb-hat.kicad_sch]
2025-11-23 Add fuse for servo
    Also update footprints with their corresponding 3d models, and start adding Net classes. Delete old 5v linear voltage regulator footprint
    [1812L110_24DR.step, pcb-hat.kicad_sch]
2025-11-23 Add PMOS for RP protection
    [SI2347DS-T1-GE3.STEP, pcb-hat.kicad_sch]
2025-11-23 Make some more space in sch
    [pcb-hat.kicad_sch]
2025-11-24 Finish LED circuitry
    Involves anti parallel LEDs and a NPN Transistor to control voltage received on the blue led
    [LM1084ISX-5.0_NOPB.step, LS_Q976.01-N1Q2-1.stp, LTST-C190GKT.step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]
2025-12-03 More net classes, fix 2 major bugs with current sensor wiring
    [pcb-hat.kicad_sch]
2025-12-04 Finish Schematic
    Add a switch and combine the 2 servos into one
    [pcb-hat.kicad_sch]
2025-12-04 Add 3d model for the switch
    [SLW-864587-2A-RA-N-D.step]
2025-12-20 Define edge cuts, JLCPCB board settings
    [pcb-hat.kicad_pcb]
2025-12-22 WIP: Fix footprints, add new jumper pad, 3d models. Begin routing
    [pcb-hat.kicad_pcb, pcb-hat.kicad_sch]
2025-12-27 Finish PCB design v0.1
    [pcb-hat.kicad_pcb, pcb-hat.kicad_sch]
2026-01-11 Fix blue LED not turning on
    [pcb-hat.kicad_pcb, pcb-hat.kicad_sch]
2026-01-11 Change digikey PN for resistors
    [pcb-hat.kicad_sch]
2026-01-18 Update schematic and reroute PCB
    See the github PR for all changes
    [AOZ6605PI-1.step, AP63300WU-7.step, ETQP4M6R8KVK.step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]
2026-01-18 Use AP63301 instead of AP63300 for lower voltage ripple during transients
    [pcb-hat.kicad_sch]
2026-01-18 Add silkscreen for encoder and buzzer
    [pcb-hat.kicad_pcb]
2026-01-21 Revert back to using 3.3V and no flyback for buzzer
    [pcb-hat.kicad_pcb, pcb-hat.kicad_sch]
2026-01-21 Add gnd pour on B.Cu, change default trace thickness to 0.2mm
    Also make the SW node to the inductor slightly closer
    [pcb-hat.kicad_pcb]
2026-01-21 Make thermal vias untented, add some reference desigs back
    [pcb-hat.kicad_pcb]
2026-01-21 Add note about cap
    [pcb-hat.kicad_sch]
2026-01-25 Add digikey pn's to caps and resistors, order board
    [pcb-hat.kicad_pcb, pcb-hat.kicad_sch]
2026-03-07 WIP: Using new pmos, voltage controller
    Removed fuse, added 7th LED, added servo RP detection and protection (pending testing)
    [pcb-hat.kicad_sch]
2026-03-09 More work on schematic
    [pcb-hat.kicad_sch]
2026-03-10 Fix servo RP detection circuit
    Start work on routing
    [pcb-hat.kicad_pcb, pcb-hat.kicad_sch]
2026-03-13 Finish routing PCB
    [3D_SRP1038CC SERIES(leadframe type).stp, LM3489MMX_NOPB.step, PJQ4437EP-AU.stp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]
2026-03-22 Save files with KiCAD v10
    [pcb-hat.kicad_pcb, pcb-hat.kicad_sch]
2026-10-07 Added bulk capacitor circuit for transmitter, exposed UART pins on Pi for transmitter communication, adjusted silkscreen to accommodate bulk capacitor
